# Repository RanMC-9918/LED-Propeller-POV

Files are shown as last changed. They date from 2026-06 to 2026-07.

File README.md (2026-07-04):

# LED-Propeller-POV

## Description

This project is a high-speed persistence-of-vision (POV) display that creates images by spinning LED strips on rotating propeller blades. The propellers should be able to rotate at 3,000 RPM and the LEDs are synchronized with the fan's position using a hall effect sensor to create an image in the air. The ESP32 microcontroller should have the bandwidth needed to live stream video to the display in real time.

Fan in alternate position

## PCB

The PCB has components needed to control the LED and motor and an ESP32 to handle communication and LED control. The 12V from the battery is fed into the motor via a motor controller (H-Bridge), then the 12V is stepped down to 5V to power the LEDs and ESP32. The signal coming out of the ESP32 is 3.3V but the LED strip needs 5V so the Bus Buffer converts the signal to 5V for the LED. All pcb traces handling the motors 12V 5A peak are thickened to reduce resistance and heat.

PCB in Kicad

## Criteria

- Must display readable text + graphic
- ≥ 64 columns × 32 rows
- Image jitter < 2° arc at speed
- Image changeable without stopping (Data stream over WiFi)
- Full RGB

## Calculations

### Speed of fan

To determine the ideal RPM of the fan we need the length of persistance of vision for the average person.

https://sky-lights.org/2023/07/24/qa-persistence-of-vision/ reports the persistance of vision to last 10 - 20ms for the average person so I used 10 milliseconds to calculate ideal RPM.

$ RPM = ((1000 / 10) * 60) / 2 = 3000 $

$10$ is length of persistance of vision.

$1000 / 10$ is the RPS, rotations per second.

The $/2$ is because the fan has 2 propellers each giving their own signal to the eye per rotation.

Note: This is ideal RPM and most LED Propeller fan designs use lower RPM for safety, although a flicker might be visible in-person.

### Clock rate of LED Strip

The clock rate of the LED strip/refresh rate limits the speed of the fan and the number of columns.

$ Hz = (RPM / 60) * N $

$Hz$ is refresh rate in Hertz.

$RPM$ is speed of fan

$N$ is number of columns.

Using 3000 RPM and 64 [columns](#criteria):

$ 3200 = (3000 / 60) * 64 $

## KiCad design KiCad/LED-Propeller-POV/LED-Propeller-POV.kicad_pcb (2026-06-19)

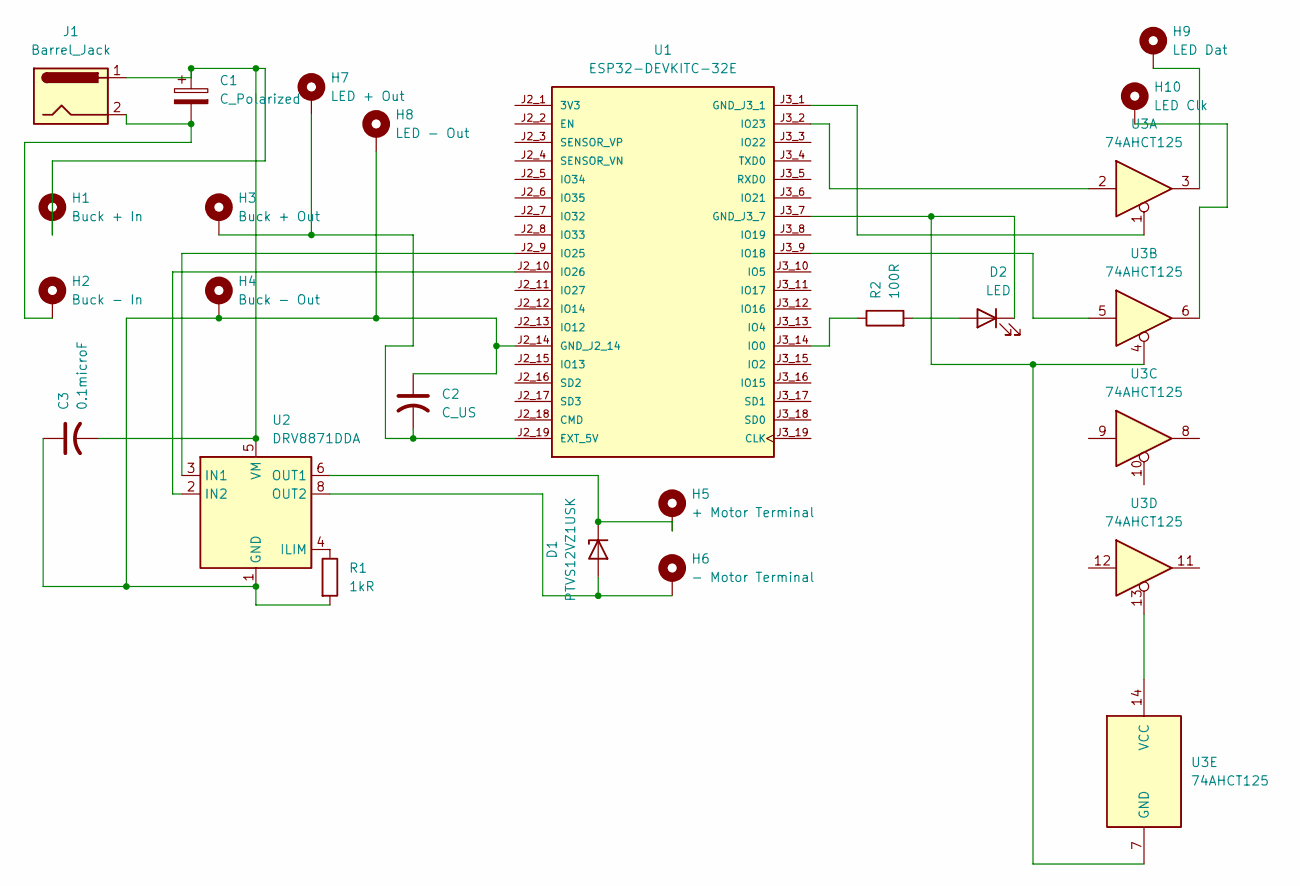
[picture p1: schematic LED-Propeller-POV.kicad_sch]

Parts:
C1: C_Polarized; CP_Radial_Tantal_D10.5mm_P5.00mm
C2: C_US; CP_EIA-3216-12_Kemet-S_HandSolder
C3: 0.1microF; CP_EIA-3216-12_Kemet-S_HandSolder
D1: PTVS12VZ1USK; Nexperia_DSN1608-2_1.6x0.8mm
D2: LED; LED_D1.8mm_W1.8mm_H2.4mm_Horizontal_O1.27mm_Z1.6mm
H1: Buck + In; TestPoint_THTPad_4.0x4.0mm_Drill2.0mm
H2: Buck - In; TestPoint_THTPad_4.0x4.0mm_Drill2.0mm
H3: Buck + Out; TestPoint_THTPad_4.0x4.0mm_Drill2.0mm
H4: Buck - Out; TestPoint_THTPad_4.0x4.0mm_Drill2.0mm
H5: + Motor Terminal; TestPoint_THTPad_4.0x4.0mm_Drill2.0mm
H6: - Motor Terminal; TestPoint_THTPad_4.0x4.0mm_Drill2.0mm
H7: LED + Out; TestPoint_THTPad_4.0x4.0mm_Drill2.0mm
H8: LED - Out; TestPoint_THTPad_4.0x4.0mm_Drill2.0mm
H9: LED Dat; TestPoint_THTPad_4.0x4.0mm_Drill2.0mm
H10: LED Clk; TestPoint_THTPad_4.0x4.0mm_Drill2.0mm
J1: Barrel_Jack; BarrelJack_CUI_PJ-063AH_Horizontal_CircularHoles
R1: 1kR; R_0603_1608Metric
R2: 100R; R_Axial_DIN0309_L9.0mm_D3.2mm_P15.24mm_Horizontal
U1: ESP32-DEVKITC-32E; MODULE_ESP32-DEVKITC-32E; PARTREV 1.4
U2: DRV8871DDA; Texas_HTSOP-8-1EP_3.9x4.9mm_P1.27mm_EP2.95x4.9mm_Mask2.4x3.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
U3: 74AHCT125; DIP-14_W7.62mm_Socket_LongPads

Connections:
unnamed: C1.2, H2.1 (1_1), J1.2
unnamed: D1.2 (A), H6.1 (1_1), U2.8 (OUT2)
unnamed: D1.1 (K), H5.1 (1_1), U2.6 (OUT1)
unnamed: D2.2 (A), R2.2
unnamed: D2.1 (K), U1.J3_7 (GND_J3_7), U3.4, U3.7 (GND)
unnamed: H9.1 (1_1), U3.3
unnamed: H10.1 (1_1), U3.6
unnamed: C2.2, H3.1 (1_1), H7.1 (1_1), U1.J2_19 (EXT_5V)
unnamed: C2.1, C3.1, H4.1 (1_1), H8.1 (1_1), R1.2, U1.J2_14 (GND_J2_14), U2.1 (GND), U2.7 (GND), U2.9 (GND)
unnamed: U1.J3_1 (GND_J3_1), U3.1
unnamed: R2.1, U1.J3_14 (IO0)
unnamed: U1.J3_9 (IO18), U3.5
unnamed: U1.J3_2 (IO23), U3.2
unnamed: U1.J2_9 (IO25), U2.3 (IN1)
unnamed: U1.J2_10 (IO26), U2.2 (IN2)
unnamed: R1.1, U2.4 (ILIM)
unnamed: C1.1, C3.2, H1.1 (1_1), J1.1, U2.5 (VM)
unnamed: U3.13, U3.14 (VCC)

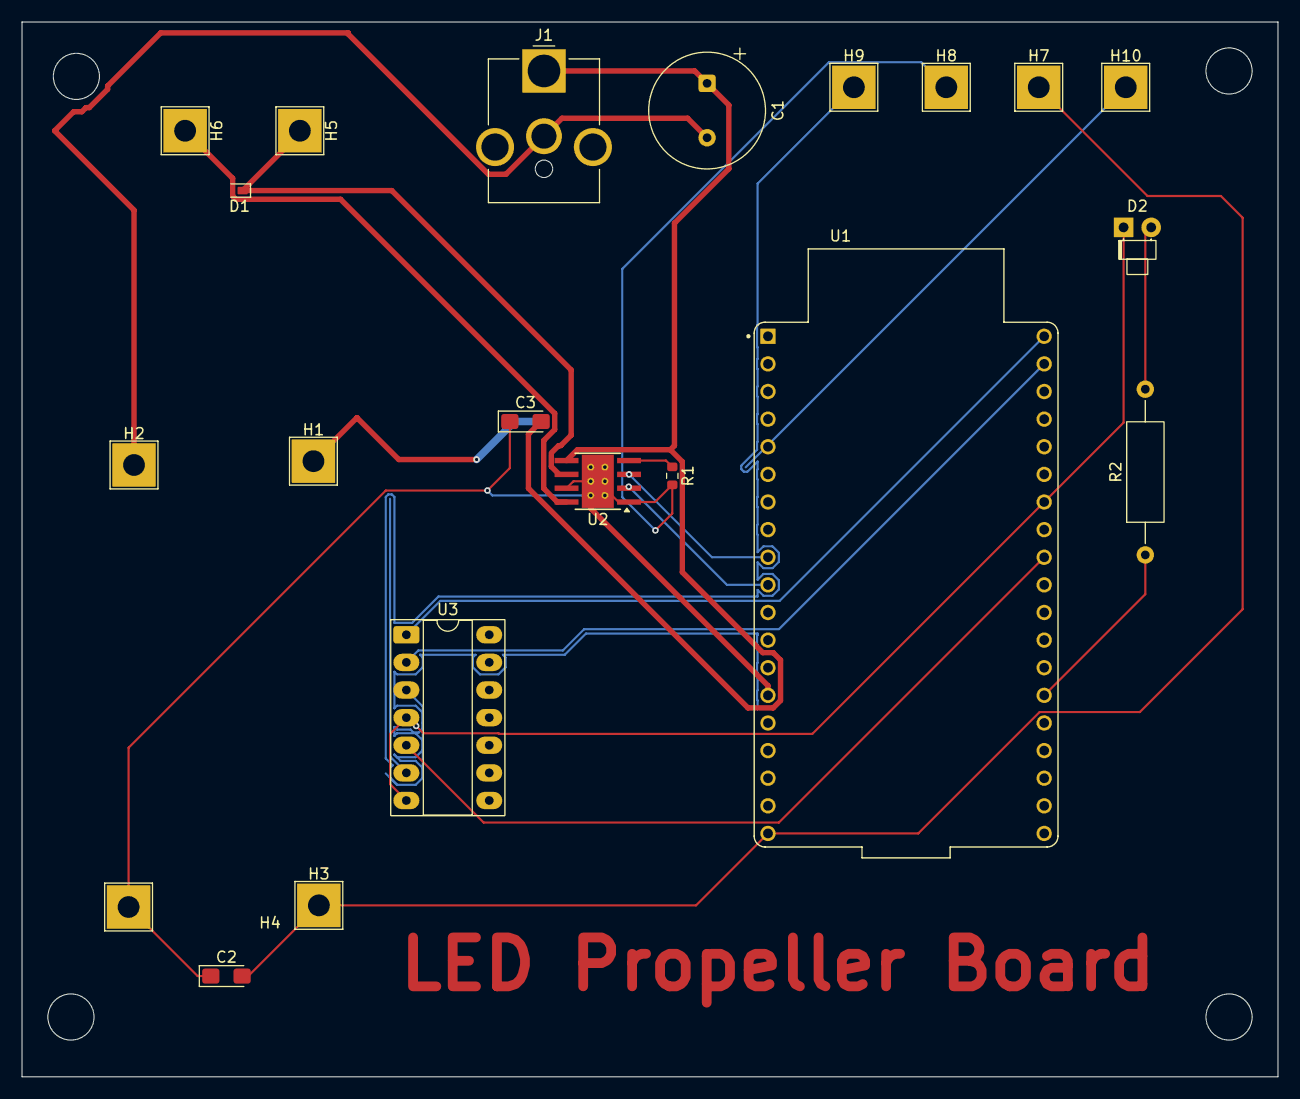
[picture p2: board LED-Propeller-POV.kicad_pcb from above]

Board: 2 copper layers, 115.5 x 97.0 mm, 21 parts (0 on the bottom side), 18 nets.

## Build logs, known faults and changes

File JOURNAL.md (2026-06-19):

# Journal

## June 11 2026

### Research (1hr 42min)

https://www.youtube.com/watch?v=GS9G-EpY_SY (Not included in time spent researching)

This video was helpful to calculate the speed and size of the LED and understanding the persistance of vision effect.

_The calculations for the speed of the fan are in the [README.md](README.md)._

https://learn.adafruit.com/motorized-pov-led-display

This guide from adafruit explained how a slip ring can be used to wire a rotating component to a stationary one without wires crossing over/damaging. Their [DotStar LED Strip](https://www.adafruit.com/product/2328) has a LED density and refresh rate that fits this projects criteria.

[DotStar LED Strip](https://www.adafruit.com/product/2328):
32 MHz clock rate > 3200 Hz required for 64 columns at 3000 RPM.

_The calculations for the clock rate of the LED strip are in the [README.md](README.md)._

144 LEDs / 2 propellers = 72 columns > 64 columns required.

144 x 144 image is 20736 bits. 3000 RPM = 50 RPS.
$ 20736 \* 50 = 1036800 $ bits per second or 1.0368 Mbps.

Looking at the ESP32 microcontroller's Wifi capabilities, it can support up to 150 Mbps so it seems to be the ideal microcontroller for this project.

### CAD Design (2hr 7min)

I worked on the chassis design that will hold all of the electronics. I spent the majority of this time on modeling dimension-accurate models of the motor, battery and slip ring in order to get the dimensions right for the chassis.

**Motor**

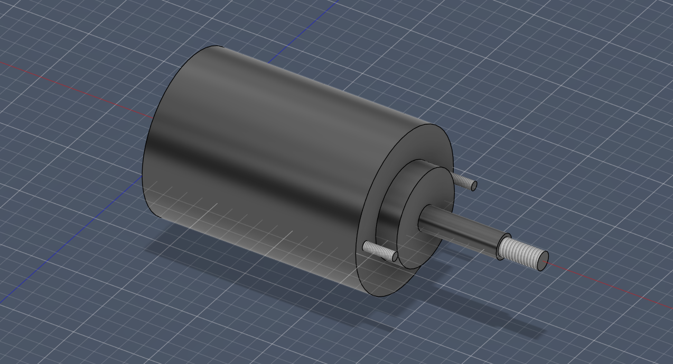
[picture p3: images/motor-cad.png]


**Battery**

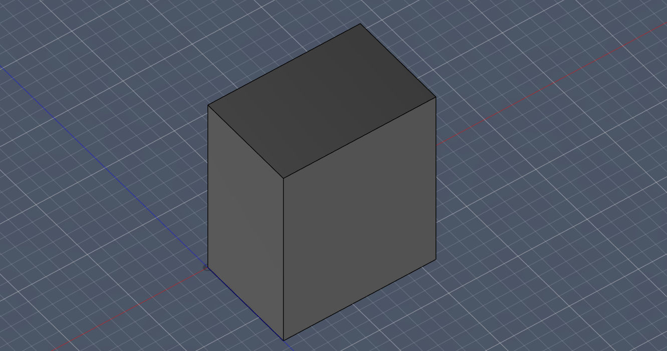
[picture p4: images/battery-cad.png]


**Slip Ring**
_Slightly edited version of [this model](https://learn.adafruit.com/motorized-pov-led-display/cad-files) from Adafruit_
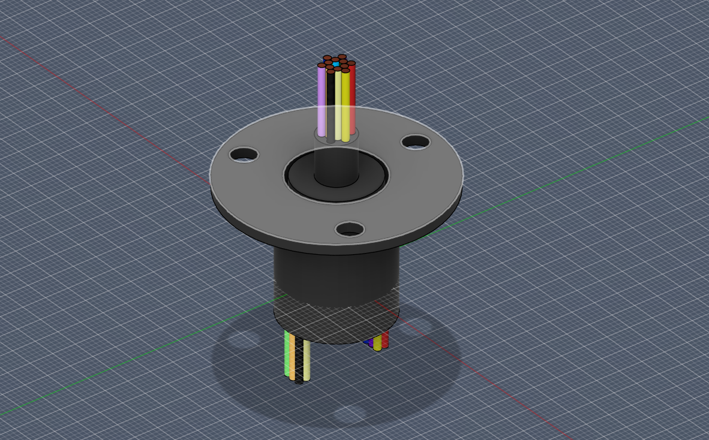
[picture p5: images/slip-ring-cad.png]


I started with a sketch on paper to get a rough idea of the design and dimensions of the chassis.
I decided on an openable design that can be easily assembled and disassembled for maintenance and repairs. I made the motor mount on the chasis and plan to fit the rest of the components into the design tomorrow.

## June 12 2026

### CAD Design (1hr 30min)

I continued working on the chassis design and added the mounts for the battery and slip ring. I also added holes for the wires to pass through and a hole on the outside of the chassis for the motor axle to pass through. The dimensions for the motor are in the amazon listing in a line drawing/sketch.

### PCB Design (1hr 57min)

I started designing the PCB for the project. I used the [ESP32 DevKitC](https://www.espressif.com/en/products/devkits/esp32-devkitc) as the microcontroller for this project and added the necessary components for power regulation and LED control. I choose to use the devboard directly on the PCB so that a usb - uart port did not need to be added manually to the PCB. (The devbooard has a built in microusb port. I added all other components like

## June 13 2026

### PCB Design (3hr 2min)

I continued working on the pcb finishing the schematic & PCB with all components. I added a buck converter to step down the 12V from the battery to 5V for the ESP32 and LED strip. I used a Bus Buffer Gate to change the ESP32's 3.3V signal to a 5V signal for the LED strip. There is a led status indicator on the board to be programmed later.

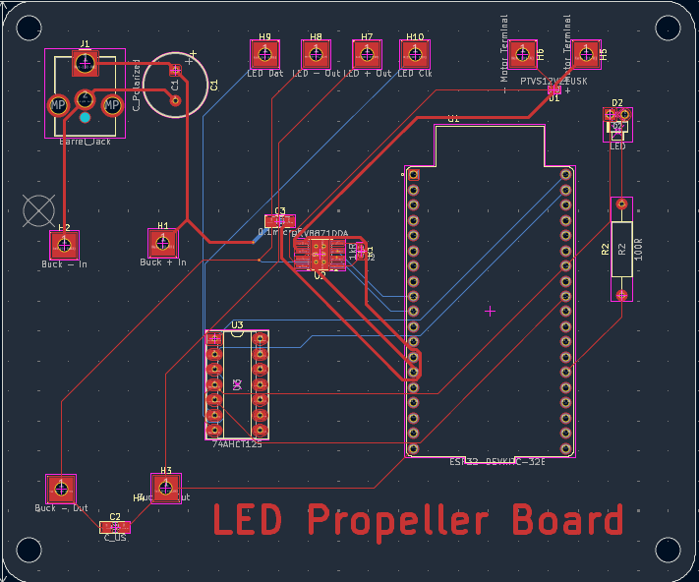
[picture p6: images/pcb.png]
PCB Design


### Research (49min)

The majority of this time was spent looking at datasheets to ensure compatibity. I had an especially hard time deciding on which motor driver to use, because many IC's have different peak current draws and need active cooling which would add complexity to the design.

## June 15 2026

### PCB Design (1hr 16min)

Had to redesign the PCB becuaae its position in the chassis had to change and the direction of the motor, battery, and led wires had to change.

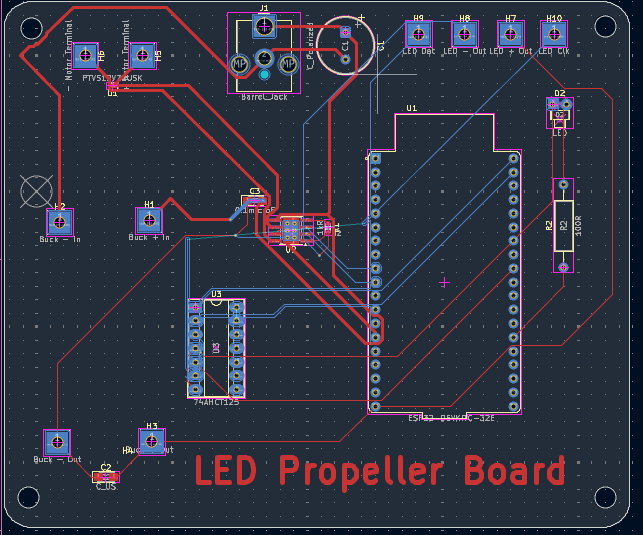
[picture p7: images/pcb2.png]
Redesigned PCB


### CAD Design (1hr 30min)

Added walls to the chassis and added the gear system to connect the motor to the propeller. I also added a mount for the slip ring. The pcb is raised off the base of the chassis to allow for better airflow and cooling. There are screw holes to hold the pcb.

## June 17 2026

### CAD Design (1hr 44min)

Finished the hull that should slide ontop of the base of the chassis. 

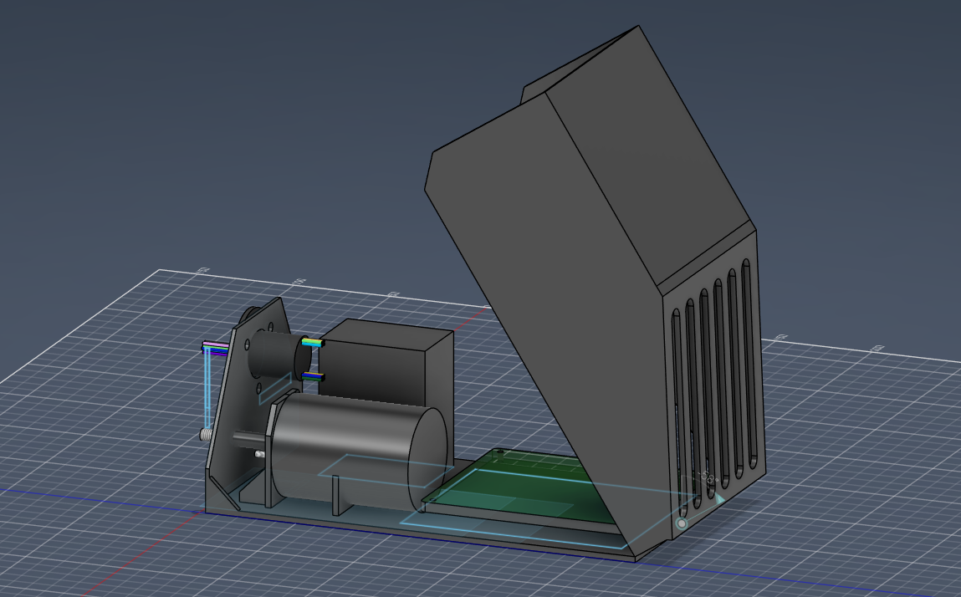
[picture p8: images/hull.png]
Lid on rest of electronics


Made airholes on the hull to allow for better cooling. 

## June 18 2026

### CAD Design (56min)

I made the fan and some prototype gears for the motor and fan. I used prototype gears because I want to use premade from a hobby store to maximize the efficiency and durability of the system.

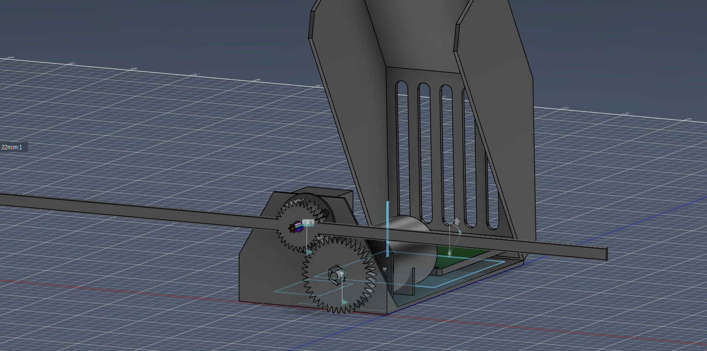
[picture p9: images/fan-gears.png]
Fan and gears


Printing the fan horizontally maximizes the tension the blades can withstand, and since centrifugal force will be pushing the blades outward, this is the ideal orientation.

## June 19 2026

### CAD Design (20min)

Made a small hole for a hall effect sensor to be placed on the motor mount to measure the RPM of the motor. This will be used to synchronize the LED display with the rotation of the fan. Also made a mount for the small permanent magnet on the rotating shaft.

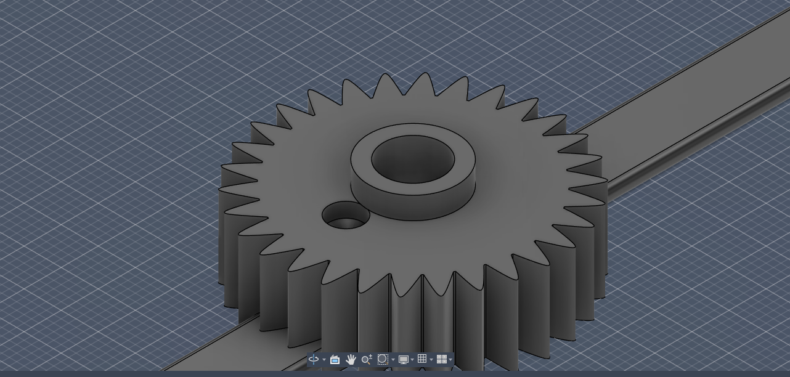
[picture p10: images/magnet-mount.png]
Hole for magnet


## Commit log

2026-06-19 jun19 update
    [LED-Propeller-POV.kicad_pcb, LED-Propeller-POV.kicad_sch]
2026-07-04 Update README with images of fan and PCB
    Added images of the fan and PCB to the README.
2026-07-04 Enhance PCB section with component details
    Added detailed explanation of PCB components and functionality.
